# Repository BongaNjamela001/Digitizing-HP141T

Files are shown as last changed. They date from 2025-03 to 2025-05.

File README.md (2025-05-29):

# HP141T Spectrogram Display Project

This repository contains the complete set of files for the HP141T Spectrogram Display project, including hardware designs, simulations, software, and documentation. The project aims to visualize time-domain spectrogram data from the HP141T spectrum analyzer on a touchscreen LCD, replicating the CRT display with a green trace and grid.

## Repository Structure

The repository is organized into the following main folders:

- **PCBs/**: Hardware design files for the HP141T emulator and Signal Conditioning Subsystem.
- **Presentation/**: Materials for project presentations.
- **Report/**: Project report and associated LaTeX files.
- **Results/**: Output data and results from the project.
- **Simulations/**: Simulation files for circuit and signal analysis.
- **Software/**: Python scripts for data processing and GUI implementation.

### PCBs
This folder contains the PCB design files for the project, divided into two subdirectories:

- **HP141T_Emulator/**: KiCad project files and Gerber files for the HP141T emulator PCB.
- **Signal_Conditioning_Subsystem/**: KiCad project files and Gerber files for the Signal Conditioning Subsystem PCB.

### Presentation
This folder includes materials prepared for project presentations:

- **Poster/**: The project poster in PDF format.
- **Oral_Assessment/**: PowerPoint presentation (`.pptx`) for the oral assessment.

### Report
This folder contains the project report and its source files:

- **LaTeX/**: LaTeX source files for the project report.
- **Final_Report/**: Compiled PDF of the final project report.

### Results
This folder stores the output data and results generated during the project. It includes CSV files (e.g., `das-data_01.csv` to `das-data_64.csv`) with time and voltage measurements used for spectrogram visualization.

### Simulations
This folder contains simulation files for circuit and signal analysis:

- **LTSpice/**: LTSpice simulation files for circuit design validation.
- **MATLAB/**: MATLAB scripts and simulation files for signal processing and analysis.

### Software
This folder includes the software developed for the project:

- **DPS/**: Python scripts for data processing (e.g., `spectrogram_display_documented.py`).
- **GUIs/**: Python scripts for graphical user interfaces to interact with the spectrogram display.

## Usage

To explore the repository:

1. **Hardware**: Use KiCad to open the PCB design files in the `PCBs/` folder. Gerber files can be used for manufacturing.
2. **Simulations**: Run LTSpice simulations directly from the `.asc` files, or use MATLAB to execute the signal processing scripts.
3. **Software**: Navigate to the `Software/DPS/` folder to run the Python scripts. Ensure dependencies like `pandas`, `matplotlib`, and `tkinter` are installed. For example:
   ```bash
   python spectrogram_display_documented.py
   ```
4. **Documentation**: View the final report in `Report/Final_Report/` or compile the LaTeX source in `Report/LaTeX/`.

## License

This project is licensed under the MIT License. See the `LICENSE` file for details (to be added).

## Contributing

Contributions are welcome! Please submit a pull request or open an issue to discuss improvements or bug fixes.

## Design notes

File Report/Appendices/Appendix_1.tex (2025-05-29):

% ----------------------------------------------------
% Introduction
% ----------------------------------------------------
\documentclass[class=report,11pt,crop=false]{standalone}
\input{../Style/ChapterStyle.tex}
\input{../FrontMatter/Glossary.tex}
\begin{document}
	% ----------------------------------------------------
	\chapter{Appendix}
	
	\section{Data Acquisition Subsystem Code}
	
	\subsection{\acrshort{das} Macros}
	
	The \acrfull{das} is implemented on the STM32H723ZG microcontroller using embedded C and the STM32 HAL library to sample the horizontal, vertical, and pen-lift signals via ADC1 pins PF10, PF9, and PF8, respectively. A 3-channel \acrshort{dma} stream is used to continuously transfer 16-bit ADC samples into a 402-element buffer, with the \texttt{DMA2\_Stream0\_IRQHandler} managing buffer events via HAL \acrshort{dma} interrupt handling.
	
	\begin{lstlisting}[language=C, label={lst:das-adc-macros}, caption={Showing macros for the \acrshort{adc} channels, \acrshort{dma} and the associated interrupts for handling streaming.}]
		/* ADC Channels */
		#define ADCx_CHANNEL                    ADC_CHANNEL_8  // V_x
		#define ADCx_CHANNEL2                   ADC_CHANNEL_7  // V_y
		#define ADCx_CHANNEL3                   ADC_CHANNEL_6  // V_z
		
		/* DMA Configuration */
		#define ADCx_DMA_CHANNEL                DMA_REQUEST_ADC1 // Master ADC1
		#define ADCx_DMA_STREAM                 DMA2_Stream0
		#define ADCx_DMA_IRQn                   DMA2_Stream0_IRQn
		#define ADCx_DMA_IRQHandler             DMA2_Stream0_IRQHandler
		
		ADC_HandleTypeDef    AdcHandleMaster;
		ADC_HandleTypeDef    AdcHandleSlave;
		
		#define ADC_BUF_SIZE 802 // 802 samples (401 samples/channel)
		volatile uint16_t adc_buffer[ADC_BUF_SIZE] = {0}; // 16-bit for interleaved data
		
		volatile int adc_error_flag = 0;
	\end{lstlisting}

	\subsection{Implementing Direct Memory Access for \acrshort{das}}
	
	The \texttt{adc\_init} function configures ADC1 and ADC2 in double-interleaved mode for continuous 16-bit sampling across three channels, with DMA handling enabled for real-time data acquisition. Although the system is configured to output 32-bit words, the use of a \texttt{uint16\_t} buffer relies on the HAL to extract the lower 16 bits of each sample.
		
	\begin{lstlisting}[language=C, label={lst:das-spectrogram-init-code}, caption={Code snippet of the \texttt{adc\_init} function which configures the double-interleaved operation of the \acrshort{adc}s.}]
		int adc_init(void) {
			ADC_ChannelConfTypeDef sConfig;
			ADC_MultiModeTypeDef multiMode;
			//...
			/* Configure ADC2 (Slave) */
			AdcHandleSlave.Instance = ADCx_SLAVE;
			AdcHandleSlave.Init = AdcHandleMaster.Init; // Same config as master
			if (HAL_ADC_Init(&AdcHandleSlave) != HAL_OK) {
				adc_error_handler();
				return -1;
			}
			
			/* Configure double-interleaved mode */
			multiMode.Mode = ADC_DUALMODE_INTERL_FAST; // Fast interleaved mode
			multiMode.DualModeData = ADC_DUALMODEDATAFORMAT_32_10_BITS;
			multiMode.TwoSamplingDelay = ADC_TWOSAMPLINGDELAY_1CYCLE;
			if (HAL_ADCEx_MultiModeConfigChannel(&AdcHandleMaster, &multiMode) != HAL_OK) {
				adc_error_handler();
				return -1;
			}
			//...
		}
	\end{lstlisting}

	\subsection{Reading Interleaved Data}
	
	\acrshort{adc} data stored in the \texttt{adc\_spectrogram} structure is processed in real-time using \acrshort{dma} half-complete callbacks, such as \texttt{HAL\_ADC\_ConvHalfCpltCallback}. This function reads interleaved $\texttt{V}_\texttt{x}$, $\texttt{V}_\texttt{y}$, and $\texttt{V}_\texttt{z}$ values from the buffer, scales them based on 16-bit resolution, and applies logic for plotting and pen-lift detection using a threshold at mid-scale (32768), with adjustments made for signal inversion and normalization as needed.
	
	\begin{lstlisting}[language=C, label={lst:das-callbacks}, caption={Showing conversion callbacks for processing \acrshort{adc} data when the \acrshort{dma} fills half.}]
		void HAL_ADC_ConvHalfCpltCallback(ADC_HandleTypeDef* AdcHandle) {
			for (int j = 0; j < ADC_BUF_SIZE/6; ++j) {
				uint32_t x_val = adc_buffer[j*3];     // V_x
				uint32_t y_val = adc_buffer[j*3+1];   // V_y
				uint32_t z_val = adc_buffer[j*3+2];   // V_z
				x_val = (x_val * adc_spectrogram->npoints) / 65536; // 16-bit scaling
				y_val = adc_spectrogram->size_y - (adc_spectrogram->size_y * y_val) / 65536;
				z_val = z_val > 32768 ? 1 : 0; // Threshold at mid-scale (~1.65 V)
				if (x_val < 5) prev_x = 0;
				if (x_val > prev_x && z_val == 0) {
					if (pending_normalization) {
						adc_spectrogram->data_normal[x_val] = adc_spectrogram->size_y/2 - y_val;
					}
					adc_spectrogram->data[x_val] = y_val + adc_spectrogram->data_normal[x_val];
					prev_x = x_val;
				}
			}
		}
	\end{lstlisting}
	
	\subsection{Enabling \acrshort{adc}'s and Peripherals on STM32H723ZG}

	The \texttt{HAL\_MspInit} function is implemented to perform essential system-level initializations for the \acrshort{das} using the STM32 \acrshort{hal} framework. It enables clocks for \acrshort{adc}s, GPIOF, and DMA2, and configures the required \acrshort{gpio} pins as analog inputs without pull-up resistors. The function also sets up \acrshort{dma} with 16-bit alignment in circular mode and links it to the \acrshort{adc}, while configuring \acrshort{nvic} interrupts to handle \acrshort{dma} transfer events efficiently.
	
	\begin{lstlisting}[language=C, label={lst:das-callbacks}, caption={Showing conversion callbacks for processing \acrshort{adc} data when the \acrshort{dma} fills half.}]
	void HAL_ADC_MspInit(ADC_HandleTypeDef *hadc) {
		GPIO_InitTypeDef GPIO_InitStruct = {0};
		static DMA_HandleTypeDef hdma_adc;
		
		if (hadc->Instance == ADCx_MASTER) {
			/* Enable clocks */
			ADCx_CLK_ENABLE();0
			ADCx_CHANNEL_GPIO_CLK_ENABLE();
			DMAx_CLK_ENABLE();
			//...
			/* Configure GPIO pins */
			GPIO_InitStruct.Pin = ADCx_CHANNEL_PIN | ADCx_CHANNEL_PIN2 | ADCx_CHANNEL_PIN3;
			GPIO_InitStruct.Mode = GPIO_MODE_ANALOG;
			GPIO_InitStruct.Pull = GPIO_NOPULL;
			//...
			hdma_adc.Init.PeriphDataAlignment = DMA_PDATAALIGN_HALFWORD; // 16-bit
			hdma_adc.Init.MemDataAlignment = DMA_MDATAALIGN_HALFWORD;
			hdma_adc.Init.Mode = DMA_CIRCULAR;
			//...
			__HAL_LINKDMA(hadc, DMA_Handle, hdma_adc);
			
			/* Configure NVIC */
			HAL_NVIC_SetPriority(ADCx_DMA_IRQn, 0, 0);
			HAL_NVIC_EnableIRQ(ADCx_DMA_IRQn);
		}
		//..
	\end{lstlisting}
	
	\section{Digital Processing Subsystem Code}
	
	\subsection{Data Formatting}
	
	To ensure compatibility between different sampling devices (such as the STM32H7 and the Picoscope), the spectrogram data structure—originally developed for an STM32F746G board—was adapted to process and store interleaved data from three ADC channels into a series of \texttt{.csv} files. The \texttt{spectrogram\_to\_csv()} function manages file creation, formats the time-stamped voltage samples, and writes them in blocks of 801 points per file to support downstream processing in the \acrshort{dps} and \acrshort{guis} subsystems.
	
	\begin{lstlisting}[language=C, label={lst:das-csv-file}, caption={Code snippet of the function for storing the interleaved sampling data in a \texttt{.csv}.}]
		int spectrogram_to_csv(spectrogram_t *s, const char *base_filename) {
			if (!s || !base_filename) return -1;
			
			const double sample_period_ms = 0.000138889; // 1 / 7.2 MSPS
			int file_index = 0;
			int point_count = 0;
			char filename[64];
			FILE *fp = NULL;
			
			for (int i = 0; i < s->npoints && !pause_flag; ++i) {
				if (point_count == 0) {
					// Open new file
					snprintf(filename, sizeof(filename), "%s%d.csv", base_filename, file_index);
					fp = fopen(filename, "w");
					if (!fp) return -1;
					fprintf(fp, "Time (ms),V_x (V),V_y (V),V_z (V)\n");
				}
				
				double time_ms = i * sample_period_ms;
				float vx = s->data_x[i] * 3.3f / 65535.0f;
				float vy = s->data_y[i] * 3.3f / 65535.0f;
				float vz = s->data_z[i] * 3.3f;
				
				fprintf(fp, "%.8f,%.8f,%.8f,%.8f\n", time_ms, vx, vy, vz);
				
				point_count++;
				if (point_count >= 801 || i == s->npoints - 1) {
					fclose(fp);
					point_count = 0;
					file_index++;
				}
			}
			
			return 0;
		}
	\end{lstlisting}
	
	\subsection{Using Piecewise Cubic Polynomial Interpolation to Smooth Display}
	
	The proposed design implements the Cubic spline interpolation algorithm which uses piecewise cubic polynomials to define a curve within different segments of the data. The code snippet in listing \ref{lst:dps-spline} illustrates how the frequency domain plot of the signal is smoothed to reduce sharp edges that can occur when using linear interpolation. The program plots the \acrshort{crt}-like background grid on the touchscreen, allowing users to analyse the input signal in the tuning section.
	
	\begin{lstlisting}[language=Python, caption={Code snippet for performing polynomial interpolation in the \acrshort{dps} to the spectrogram a smoother appearance.}, label={lst:dps-spline}]
	from scipy.interpolate import CubicSpline
	#...
	# Perform cubic spline interpolation
	def interpolate_data(time_ms, power_db):
		cs = CubicSpline(time_ms, power_db)
		time_smooth = np.linspace(time_ms[0], time_ms[-1], 1000)  # Increase resolution
		power_smooth = cs(time_smooth)
		 plt.clf()
		ax = plt.gca()
		
		# Plot with CRT styling using spline-interpolated data
		ax.plot(time_smooth, power_smooth, color='limegreen', linewidth=2)
		
		# CRT-like background and grid
		ax.set_facecolor('black')
		fig.patch.set_facecolor('black')
		ax.grid(True, color='gray', linestyle='--', linewidth=0.5)
		
		# Grid divisions: 10 (time), 8 (amplitude)
		time_max = time_ms[-1]
		ax.set_xticks(np.linspace(0, time_max, 11))
		ax.set_yticks(np.linspace(0, 80, 9))
		
		# Labels and title
		ax.set_xlabel('Frequency (GHz)', color='white', fontsize=12)
		ax.set_ylabel('Amplitude (dB)', color='white', fontsize=12)
		ax.set_title('HP141T Spectrogram', color='white', fontsize=14)
		ax.tick_params(axis='both', colors='white')
		
		# Set axis limits
		ax.set_xlim(0, time_max)
		ax.set_ylim(0, 80)
		
		canvas.draw()
		logging.info("Frequency domain plot updated successfully with spline interpolation")
	\end{lstlisting}

	\section{Graphical User Interface Code}

	\subsection{Pause Functionality Implemented on the Single-Board Computer}
	The code snippet below is used to flag the STM32H723ZG connected to the single-board \acrshort{rpi} 4B to pause data sampling. The code also illustrates enabled logging for debugging and getting feedback on the user's actions.
	\begin{lstlisting}[language=Python, caption={Code snippet for function associated with the pause function in latex.}, label={lst:guis-pause-function}]
	# Global pause flag
	pause_flag = False
	
	def pause_recording():
		global pause_flag
		pause_flag = True
		status_label.config(text="Recording Paused")
		logging.info("Recording paused by user")
	\end{lstlisting}

	\subsection{Enabling the \acrfull{phm}, \acrfull{avm} and \acrfull{rwm} Display Modes}
	The \acrshort{phm} tracks and displays the maximum value seen for each data point and is updated per scan. The \texttt{hp141t} Python module includes a \texttt{SpectrumProcessor Class} for updating the \texttt{time\_data} with the maximum value at each index. 
	
	\begin{lstlisting}[language=Python, caption={Code snippet for enabling the \acrshort{phm} when the user presses the \texttt{PHM} button on the screen.}, label={lst:guis-phm}]
		 # Update mode-specific data
		if self.mode == 'PHM':
			np.maximum(self.peak_data, power_db, out=self.peak_data)
			return self.peak_data
		elif self.mode == 'AvM':
			if self.scan_count == 1:
				self.avg_data = power_db
			else:
				self.avg_data = (self.avg_data * (self.scan_count - 1) + power_db) / self.scan_count
			return self.avg_data
		else:  # RwM
			self.raw_data = power_db
			return self.raw_data
	\end{lstlisting} 

	\subsection{System Documentation and Tutorial for Users}
	
	A \texttt{HELP} button is included to enhance the usability of the system, in line with SRO6. The tutorial is displayed in a read-only \texttt{Text} widget and explains the system to users.
	
	\begin{lstlisting}[language=Python, caption={Code snippet for creating a pop-up window with a tutorial when the user interacts with the \texttt{HELP} button.}, label={lst:guis-show-help}]
		def show_help():
			"""Display a tutorial window"""
			help_window = tk.Toplevel(root)
			help_window.title("Help - HP141T Spectrogram Tutorial")
			help_window.geometry("400x300")
			help_window.configure(bg='black')
			
			# Tutorial text
			tutorial_text = """
			=== HP141T Spectrogram Tutorial ===
			
			Welcome to the HP141T Spectrogram Display!
			This system visualizes data from the HP141T spectrum analyzer on a touchscreen LCD.
			
			**Purpose:**
			- Displays time-domain spectrogram data (0 to 80 dB amplitude, time sweep).
			- Replicates the CRT display with a green trace and grid.
			
			**Modes:**
			- **Peak Hold Mode (PHM):** Shows the largest value seen at each time point, updated per scan.
			- **Average Mode (AvM):** Displays the running average of values at each time point, updated per scan.
			- **Raw Mode (RwM):** Shows the latest value, overwriting previous data during each scan.
			
			**Usage:**
			- **Mode Selection:** Tap 'Peak Hold Mode', 'Average Mode', or 'Raw Mode' to switch display modes.
			- **Pause:** Tap 'Pause Recording' to stop updates.
			- **Help:** Tap 'Help' to view this tutorial.
			- Navigate using touchscreen gestures if supported by future updates.
			
			**Notes:**
			- Data is loaded from 'spectrogram_data_X.csv' files in /home/pi.
			- Contact support for issues (log at /home/pi/spectrogram_display.log).
			
			Close this window to return to the display.
			"""
			
			# Create and configure text widget
			text_widget = tk.Text(help_window, bg='black', fg='white', font=('Courier', 10), wrap='word')
			text_widget.insert(tk.END, tutorial_text)
			text_widget.config(state='disabled')  # Make read-only
			text_widget.pack(expand=True, fill='both', padx=10, pady=10)
	\end{lstlisting} 
	\ifstandalone
	\bibliography{../Bibliography/References.bib}
	\printnoidxglossary[type=\acronymtype,nonumberlist]
	\fi
\end{document}
% ----------------------------------------------------

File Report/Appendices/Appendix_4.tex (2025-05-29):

% ----------------------------------------------------
% Introduction
% ----------------------------------------------------
\documentclass[class=report,11pt,crop=false]{standalone}
\input{../Style/ChapterStyle.tex}
\input{../FrontMatter/Glossary.tex}
\begin{document}
	% ----------------------------------------------------
	\chapter{Appendix}

	\section{Graduate Attributes}
		
	\begin{table}[ht!]
		\centering
		\begin{tabular}{|c|m{15em}|m{20em}|}
			\hline
			\textbf{GA} & \textbf{Requirement} & \textbf{Justification and Section in Report} \\
			\hline
			1 & \textbf{Problem-solving} &
			The project focuses on digitizing and modernizing the HP141T spectrum analyzer by identifying engineering challenges such as analog signal emulation, safe ADC interfacing, and display integration. Problem-solving was guided by engineering fundamentals to replicate the HP141T's behavior while addressing obsolescence. \textit{See Chapters 2 and 3.} \\
			\hline
			4 & \textbf{Investigations, experiments and data analysis} &
			The project involved unit, integration, and acceptance testing of the emulator and digitized system. Measurements from analog signals were sampled, processed, and evaluated using oscilloscope and data analysis tools. Results were used to confirm emulation fidelity. \textit{See Chapter 5.} \\
			\hline
			5 & \textbf{Use of engineering tools} &
			Modern tools such as KiCad (PCB design), STM32CubeIDE (embedded development), Python (data processing and GUI), and the Picoscope software were used throughout. These tools enabled simulation, design validation, and visualization. \textit{See Chapter 3.} \\
			\hline
			6 & \textbf{Professional and technical communication} &
			Weekly Microsoft Teams meetings were held with the supervisor, and updates were communicated clearly. Project progress, testing results, and implementation steps were documented in the report. A full BoM and Gantt chart were created. \textit{See Chapter 1 and Appendices.} \\
			\hline
			8 & \textbf{Individual work} &
			All major system components—hardware design, firmware development, data processing, and GUI rendering—were independently developed. Feedback was incorporated iteratively throughout the project. \textit{See entire report.} \\
			\hline
			9 & \textbf{Independent learning ability} &
			The project required in-depth understanding of legacy analog circuitry, signal conditioning, ADC interfacing, and embedded development. This knowledge was self-acquired through datasheets, application notes, and literature. \textit{See Chapter 2 and 3.} \\
			\hline
		\end{tabular}
		\caption{Summary of Graduate Attributes Achieved in the Digitized HP141T Project}
		\label{tab:graduate-attributes-hp141t}
	\end{table}

	\ifstandalone
	\bibliography{../Bibliography/References.bib}
	\printnoidxglossary[type=\acronymtype,nonumberlist]
	\fi
\end{document}
% ----------------------------------------------------

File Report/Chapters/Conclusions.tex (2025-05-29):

% ----------------------------------------------------
% Conclusions
% ----------------------------------------------------
\documentclass[class=report,11pt,crop=false]{standalone}
\input{../Style/ChapterStyle.tex}
\input{../FrontMatter/Glossary.tex}
\begin{document}
% ----------------------------------------------------
\chapter{Conclusions \label{ch:conclusions}}

The experimental testing of the digitized HP141T system, incorporating the HP8555A and HP8552B plug-in sections, has yielded valuable insights into its performance and alignment with the specified functional requirements. The results demonstrate a mixed outcome, with significant achievements in certain subsystems tempered by challenges in others, necessitating further refinement.

The HP141T System Test Results, utilizing the Siglent SDG1010 waveform generator and Picoscope 2204 USB oscilloscope, successfully approximated the vertical output with satisfactory accuracy, achieving a peak-to-peak voltage deviation of approximately 10\% from the expected values. The Picoscope proved to be a reliable measurement tool, and the sinusoidal approximation at 10 kHz provided a suitable basis for testing, despite limitations in replicating the full range of the original HP141T outputs. However, the horizontal and pen-lift outputs could not be accurately emulated due to waveform shape discrepancies and voltage range constraints, highlighting the need for alternative hardware or calibration methods to fully replicate the HP8552B behavior.

The HP141T Emulator Subsystem Test Results revealed significant deviations from expected performance, attributed to the use of E6 series resistors and adjusted capacitor values instead of the recommended E24 series. The failure of the emulator to produce the correct vertical (0 to 3.0 V), horizontal (±4.75 V sawtooth), and pen-lift (0 to 14 V) outputs underscores the sensitivity of the XR2206-based design to component tolerances. While the power rails met specifications, further iterations are required to enhance waveform fidelity and ensure compatibility with downstream systems.

In contrast, the SCS performed admirably, with unit tests confirming its ability to invert and scale the vertical input from -0.8 V to 0 V to the ADC-compatible 0 V to 3.3 V range. The subsystem handled noisy inputs effectively, maintaining output within the desired range, though clipping effects were observed at higher amplitudes, mitigated somewhat by increasing the input frequency to 300 kHz. These results validate the SCS design and its robustness against real-world signal variations.

The Data Acquisition Subsystem DAS, adapted to use the Picoscope 2204A due to the unavailability of the STM32H723ZG microcontroller, successfully generated CSV files with 6257 data points at a 3.3 kHz sampling rate, exceeding the required 801 samples per second. This adaptation, while affecting real-time performance, ensured data integrity for downstream processing, demonstrating the system's flexibility in leveraging alternative hardware.

The Digital Processing Subsystem DPS and Graphical User Interface Subsystem GUIS, implemented on the Raspberry Pi 4B, met all unit test criteria. The DPS accurately scaled voltages to decibels, retained peak amplitudes, averaged spectrograms, and interpolated sparse data, while the GUIS provided near real-time updates (50-100 ms latency), reliable mode switching, and a faithful 8x10 grid display with CRT styling. These results affirm the software's robustness and usability, closely emulating the original HP141T's visual output.

Overall, the digitized HP141T system achieves a high degree of fidelity in its software components (DPS and GUIS) and signal conditioning SCS, meeting the functional requirements for display accuracy, responsiveness, and user interaction. However, hardware-related limitations in the emulator and original system approximation highlight areas for improvement, particularly in component selection and waveform emulation. Future work should focus on refining the HP141T Emulator with precise E24 components, exploring higher-voltage waveform generators for the pen-lift output, and optimizing the DAS for real-time performance with the intended microcontroller. These enhancements will further align the system with the original HP141T's capabilities, ensuring a comprehensive and accurate digital replica.

% ----------------------------------------------------
\ifstandalone
\bibliography{../Bibliography/References.bib}
\printnoidxglossary[type=\acronymtype,nonumberlist]
\fi
\end{document}
% ----------------------------------------------------

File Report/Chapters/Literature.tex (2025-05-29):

% ----------------------------------------------------
% Literature Review
% ----------------------------------------------------
\documentclass[class=report,11pt,crop=false]{standalone}
\input{../Style/ChapterStyle.tex}
\input{../FrontMatter/Glossary.tex}
\begin{document}
\ifstandalone
\tableofcontents
\fi
% ----------------------------------------------------
\chapter{Literature Review \label{ch:literature}}
\vspace{0.25cm}
% ----------------------------------------------------
The aim of this chapter is to conceptualize the operation of spectrum analyzers and establish a theoretical foundation for the frequency analysis techniques applied to produce the correct output. This conceptualization is then integrated with a broader review of digitizing and modernizing the display of spectrum analyzers.

In circumventing design limitations of spectrum analyzer displays, it is prudent to survey the most suitable hardware components. This is particularly true for the case where electronic components are required to perform in a broad frequency bandwidth. For example, for high frequency signals, the Nyquist theorem indicates that the ADC is required to have a sample at a frequency that is more than double the frequency of the output signal. Furthermore, the challenge of presenting signals in the frequency domain using electronics exists due to the fact the input signal to the ADC holds information about frequency in the time domain. Therefore, the investigation of literature that is presented in this chapter aims to provide a motivation for the design decisions taken in digitizing and modernizing the HP141T display.

The chapter begins with an evaluation of the frequency domain analysis theory that is applied in the operation of signal analyzers. Then, the different principles that distinguish different types of analyzers are explored to form the basis understanding the expected behaviour of a spectrum analyzer with specific settings. Following descriptions of the operation of spectrum analyzers from literature, the chapter includes a review of the investigation into different techniques for digitizing analyzer displays. This also includes a review of the different electronic components and techniques for digitizing frequency information in order to survey available hardware options that can be selected for a cost effective implementation. Finally, a broad discussion is included on different types of displays for analyzers in literature and a critique of the literature is provided to outline the purpose of the proposed design. 

\section{Mitigating Spectrum Analyzer Obsolescence: A Historical Perspective}

\subsection{Introduction to Spectrum Analysis}

A spectrum analyzers \acrshort{sa}s is a critical instrument for investigating properties of physical phenomena that can be interpreted through power and frequency characteristics of analog signals derived from voltage measurements. This project differentiates between spectrum analyzers and oscilloscopes such that spectrum analyzers are instruments that display waveforms in the frequency domain and oscilloscopes as instruments that operate in the time domain. However, the paper recognizes their significance in signal processing applications, as well as some of the shared similarities in their subsystems. 

As such, the following section is a review of the history and applications of spectrum analyzers and oscilloscopes to establish the context of the project. By assimilating literature on the applications of these instruments in engineering, the section also aims to formulate design guidelines from previous works that can improve the operation of the digitized HP141T, thereby satisfying user and functional requirements. 

\subsection{Early Developments in Waveform Analysis}

The evolution of \acrshort{sa}s is closely linked to that of the oscilloscope. In a review of the history and technology of oscilloscopes, Pereira attributed the invention of the electromagnetic oscillograph to the French physicist, Andr\'{e}-Eugene Blondel \cite{pereira2006}. Oscillographs were devices that used a pen attached to a moving coil to trace an ink record on a rotating paper chart \cite{pereira2006}. According to Herres, the motivation for the invention of oscillographs was to extract waveforms from acoustic and electrical phenomena, however, the devices had a severely limited frequency response and bandwidth because of the inertia of the pen and ink recording equipment \cite{herres2020}. Ultimately, the operation of these devices was restricted by the working principle based on mechanical devices which limited the bandwidth in the range of $10$-$\SI{19}{\hertz}$ \cite{pereira2006}.

\begin{wrapfigure}{r}{0.5\textwidth}
	\centering
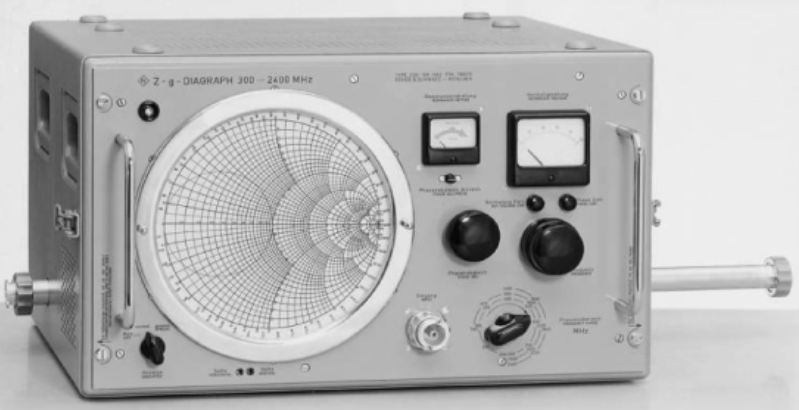
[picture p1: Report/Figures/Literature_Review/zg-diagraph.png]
	
	\caption{The Z-G Diagraph by developed by Rohde \& Schwarz with a Schmidt chart for measuring complex parameters \cite{rytting2008arftg}.}
	\label{fig:zg-diagraph}
\end{wrapfigure}

Following the invention of the oscillograph, available waveform analysis tools included contact diode and vacuum tubes as the only form of signal detectors \cite{vollinger2023}. Technologies such as the slotted line and phase bridges became the standard instruments for measuring amplitude and frequency but were often slow and tedious \cite{rytting2008arftg}. In 1933, Rohde \& Schwarz developed the improved Z-G system which was the first to directly indicate complex parameters on a Schmidt chart as shown in figure \ref{fig:zg-diagraph} \cite{rytting2008arftg}.  

\subsection{Advancements in Spectrum Analysis Technology}
 
The first commercially available real-time signal analyzers (\acrshort{rtsa}s) were introduced in the 1960s by Federal Scientific to process data up to $\SI{20}{\kilo\hertz}$ through a single filter that could change modes in milliseconds \cite{deery2007}. These devices were designed for analyzing mechanical faults and failures in rotating machinery and for investigating vibratory motions of components, systems and structures \cite{deery2007}. In contrast to the the \acrshort{sa}s introduced in the 1960s for characterizing rotary machinery, this paper is focuses on \acrshort{sa}s that were designed for displaying wide-band signals up to the K-band of microwave signals. 

Rapid progress in semiconductor technology and microwave elements laid a foundation for the developed first waveform instrumentation devices with $\SI{1}{\giga\hertz}$ bandwidth \cite{vollinger2023}. With the advent of wireless network technologies, \acrshort{sa} developments became focused on high frequency instrumentation which had to meet testing requirements of first generation technologies such as the \acrfull{amps} operated at frequencies at $\SI{800}{\mega\hertz}$ to $\SI{900}{\mega\hertz}$. Vector network analyzers were introduced as an extension of spectrum analyzers capable of displaying amplitude and phase relative to a reference signal \cite{helfrick2012}. 

\subsection{Early Modifications to Spectrum Analyzers (1960s - 1980s)}

\begin{wrapfigure}{l}{0.6\textwidth}
	\centering
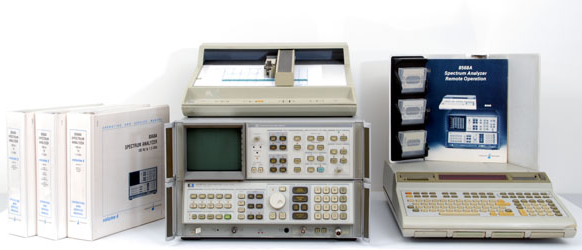
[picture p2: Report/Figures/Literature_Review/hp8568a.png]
	
	\caption{The HP8568A spectrum analyzer which was the first spectrum analyzer from Hewlett-Packard Company to include a microprocessor in the 1970s.}
	\label{fig:hp8568a}
\end{wrapfigure}

Motivated by applications in network analysis and microwave engineering, Hewlett-Packard developed the first fully calibrated spectrum analyzer that capable of sweeping broad frequency ranges \cite{adam1984microwave}. After the introduction of easily-operated wideband network analyzer equipment in 1967, Hewlett-Packard Co. released a network analyzer with a range of $\SI{100}{\kilo\hertz}$ to $\SI{110}{\mega\hertz}$. In particular, the company released the Model 8407A which could resolve amplitude of up to $\SI{0.05}{\decibel}$ on a plug-in polar \acrfull{crt} display to show amplitude and phase \cite{rytandnetwork1969}. The aim of the display was so that the device could be used with Smith chart overlay, or reflection coefficient measurements \cite{rytandnetwork1969}. 

\begin{wrapfigure}{r}{0.40\textwidth}
	\centering
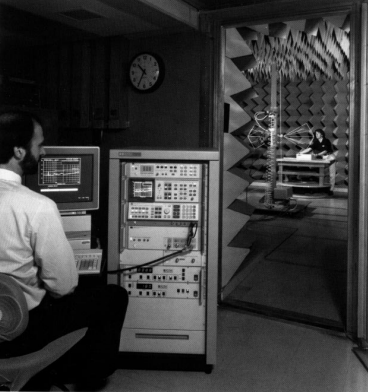
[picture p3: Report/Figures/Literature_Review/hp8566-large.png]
	
	\caption{Illustrating the size of early spectrum analyzer setups. Digitization and modernization of these devices was also focused on reducing their size in order to improve portability.}
	\label{fig:hp56xx-large}
\end{wrapfigure} 

In 1982, D'Addario proposed the implementation of Hewlett-Packard Model 8410A network analyzer as a reflectometer in a system which included an Apple II Plus computer for performing computations of the short-open-load method of calibrating and correcting errors of signals in the S-band of the microwave region of the electromagnetic spectrum \cite{d1982computer}. D'Addario stated that the advantage of implementing a computer-based system was in the software substituted a short delay line for open circuit calibration \cite{d1982computer}. In addition, the software was mostly in Applesoft Basic that featured assembly language subroutines for performing complex arithmetic and controlling the interface \cite{d1982computer}. Similarly, the proposed design in this project aims to exploit the advantages of computerization by introducing functions and libraries for performing digital signal processing tasks and controlling the \acrfull{gui}. 

Another modification to the HP8410 was performed by NASA's Terry and Kunath in 1990, where the \acrshort{sa} was used as an automated far-field antenna range receiver \cite{terry1990}. The system included external mixers capable of harmonic mixing up to $\SI{18}{\giga\hertz}$, \acrfull{adc}s, and interfaced with an external computer \cite{terry1990}. Terry and Kunath noted that the phase and amplitude signals could be converted to digital signals by using either \acrshort{adc}s or by using a digital voltmeter \cite{terry1990}. The authors used a HP308 personal computer with two processors that operated in the DOS 3.3 and HP Basic 5.0 environments, respectively \cite{terry1990}. The computer was employed as the system controller with programs for creating and editing control files for swept frequency, viewing radiated power level data, and running tests with parameters saved in files to be executed or edited at a later time \cite{terry1990}. Consequently, the designer needs to consider file formats, file sizes and file transmission in the process of digitizing a \acrshort{sa}. This is particularly true when the system processes are performed across different devices and programs which may support different file formats and file sizes. 
 
\begin{wrapfigure}{l}{0.6\textwidth}
	\centering
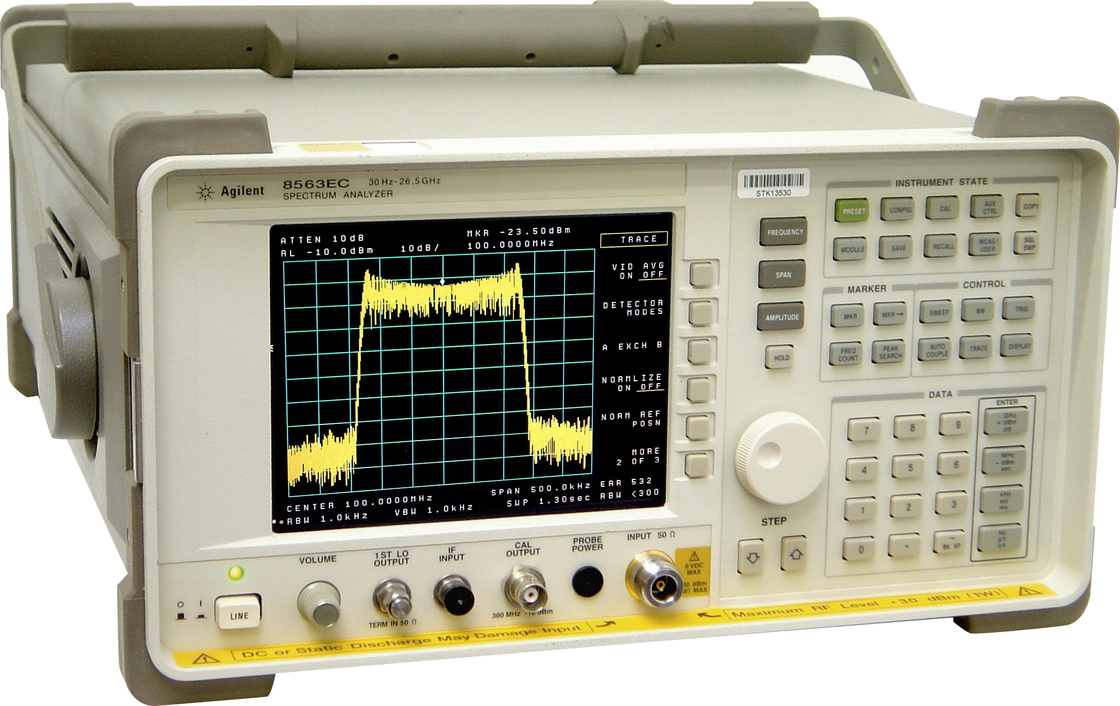
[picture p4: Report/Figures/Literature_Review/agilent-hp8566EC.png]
	
	\caption{The Agilent 8560EC is shown with a \acrshort{lcd} display. This was an improvement over the 8560E model which had a \acrshort{crt} display.}
	\label{fig:agilent-hp8560e}
\end{wrapfigure} 

\subsection{Commercial Digitization of Spectrum Analyzers}

HP85XX spectrum analyzers replaced the HP84XX analyzer series as the first \acrshort{sa}s with synthesized frequency sweeps and an \acrshort{adc} converter for sampling a video signal and displaying it on a \acrshort{crt} screen. The HP85XX series expanded the capabilities of spectrum analyzers, however, earlier versions of these devices were large as shown in figure \ref{fig:hp56xx-large}, where a technician is shown alongside a HP8566B \acrshort{sa} at the heart of two EM1 receivers \cite{hp8566}. Significant improvements to this series of \acrshort{sa}s were realised over previous versions when the HP8568A automatic \acrshort{sa}, shown in figure \ref{fig:hp8568a}, was introduced with a microprocessor controlling its operation. 

In the 2000s, Agilent Technologies mordenized the front and rear panels of HP8560E Model spectrum analyzers,  by introducing \acrshort{lcd} color display interfaced with a \acrshort{lcd} driver board and \acrshort{vga} port located that did not require a user interface \cite{hp8560ec}. Further additions included \acrshort{adc} circuitry integrated into the controller board \cite{hp8560ec}. These improvements also translated into better portability of the system as shown in \ref{fig:agilent-hp8560e}. 

\subsection{Obsolescence Mitigation and Modernization Strategies}

Overtime as prices of new spectrum analyzers increased rapidly, researchers opted to use older \acrshort{sa}s instead of replacing them. Research into strategies for mitigating risks related to the obsolescence of older \acrshort{sa} models was conducted by Hoppin in 2002, where particular focus was allocated to HP8566/68 \acrshort{sa}s in automated test equipment \cite{hoppin2002}. Hoppin stated that dependence on obsolete and unsupported equipment increased the risk of system and that as \acrshort{sa}s aged, the time required for repair and the cost of replacement increases rapidly \cite{hoppin2002}. As a result of the inevitable obsolescence, Hopping proposed three strategies for dealing with the aged devices, namely, the \textit{stockpile}; the \textit{redesign}; and \textit{migration} strategies. The stockpile strategies requires industry organizations to identify sources of spare replacement components and instruments, and offer repair and calibration services \cite{hoppin2002}. 

This project follows a strategy similar to the redesign strategy proposed by Hoppin in which automated test equipment program managers are required to assess the feasibility of introducing replacement instrument specifications, feature and capability requirements \cite{hoppin2002}. Hoppin noted that one of the risks of applying the redesign strategy is that software projects are notoriously hard to manage to scope, budget and schedule \cite{hoppin2002}. Additionally, since the devices have aged significantly, the languages, tools and methods originally used may be lost, requiring designers to apply reverse engineering techniques \cite{hoppin2002}. To mitigate the costs from applying the redesign process, Hoppin described three main components that need to be considered, namely, test code creation, test instrumentation, purchase and integration, and revalidation measurements and results \cite{hoppin2002}. 

In a similar research published in 2010, Wolle discussed the various aspects related to replacement of obsolete instruments to overcome the challenges that arise when newer versions are not compatible with previous systems \cite{wolle2010}. In the paper, Wolle postulated that an emulation strategy can help designers to incorporate new test instruments to migrate from obsolete instruments \cite{wolle2010}. In addition, Wolle noted that when assessing version migration strategies, modernizing test equipment typically has much higher costs but leads to greater reliability and faster tests \cite{wolle2010}. This was first noted by Hoppin who detailed two risks of implementing a migration strategy as low compatibility and disagreement in measurement results due to differences in architectural and measurement methods between legacy and newer-generation platforms \cite{hoppin2002}.

In a 2014 paper by Iglesias et al., the high cost of spectrum analyzers is also noted as a primary motivation for further developing spectrum analyzer designs \cite{iglesias2014}. Iglesias et al. also indicated that because \acrshort{sa}s employ non-invasive methods to detect machine failures in real-time, the devices need to be continually upgraded to reduce failures by improving the efficiency of industrial monitoring systems \cite{iglesias2014}. Following the motivation for improving \acrshort{sa}s, Iglesias et al. postulated that modernization of \acrshort{sa}s was primarily enabled by the fast evolution of \acrshort{adc}s and \acrfull{dsp}s which offer the opportunity to implement multiple methods for spectrum estimation such as Barlett and Welch's methods for averaging periodograms \cite{iglesias2014}. The authors listed devices such as \acrfull{fpga}s, \acrfull{asic}s, general-purpose \acrshort{cpu}s, and \acrfull{gpu}s as feasible candidates for digitizing \acrshort{sa}s \cite{iglesias2014}, however, \acrshort{asic}s were listed as the best implementation with respect to area, power, and speed \cite{iglesias2014}. 
%Continuing to as a pioneer in spectrum analysis in the 1980s, the Hewlett-Packard Company launched the HP8510 \acrfull{vna} System that featured an on-board computer that performed error correction of all parameters in real-time \cite{adam1984microwave}. The full \acrshort{sa} system had an extended frequency range with a single-sweep capability of $\SI{45}{\mega\hertz}$ to $\SI{26.5}{\giga\hertz}$. The measurement and computational power of the HP8510A vector analyzer was provided by microprocessor-based control which enabled the system to offer $\SI{80}{\decibel}$ to $\SI{100}{\decibel}$ range. 
\subsection{Conclusion}

In conclusion, the evolution of spectrum analyzers is characterized by advancements in metrological accuracy in waveform analysis, a migration from analog to digital processing, as well as improvements in functionality and hardware of the user interface. From early mechanical oscillographs to modern digital spectrum analyzers, each technological advancement has been motivated by the need for higher frequency capabilities and improved usability. Technological advancements have culminated in the introduction of computerized control using microprocessors and \acrshort{adc}-based systems that support more efficient signal analysis in the digital time domain.

A primary conclusion that can be drawn from the historical review of \acrshort{sa}s is that modernization strategies for obsolete instruments must balance cost, functionality, and compatibility with newer technologies. \acrshort{sa}s and network analyzers like the HP8410A and HP8568A introduced microcontrollers to automate functions. More recent trends that were introduced with Agilent Technologies' \acrshort{sa}s emphasized \acrshort{gui}s, software-based processing, and integration with digital communication protocols. 

In this project, the digitization of the HP141T spectrum analyzer builds on the primary ideas presented in history on the modernization of spectrum analyzers. Similar to implementations in history, the design proposed in this paper leverages modern single-board computing, digital displays, and software-based signal processing techniques for implementing the redesign strategy for circumventing the obsolescence of the \acrshort{sa}. Furthermore, this project aims to retain the core measurement functionalities of the original device while introducing intuitive graphical interfaces and improved data handling capabilities. The following sections discuss similar works and the challenges that researchers overcame in digitizing and modernizing spectrum analyzers.

\section{A Preview of the Operation of Spectrum Analyzers to Establish the Context for Digitization and Modernization}

Formulating an understanding of the internal operation of the HP141T system is critical for extending functionality through digitization and modernization. In this regard, this project establishes the context of the term digitization as the development of a system which converts the analog signals from the \acrshort{sa} into digital values that are processed on a computer. The context for the term \texttt{digitization} and its usage were explored through literature as described in this section. Key related works were collated and focus is placed on detailing the internal path of an analog signal through the major components of \acrshort{sa}s in general.

The term \textit{modernization} is also clarified through collated literature. In particular, this section details features of modern \acrshort{sa}s and their user interfaces which largely depend on the employed display type. By redesigning the display of the HP141T, the project aims to improve the overall performance of the system with respect to power consumption, ease-of-use, portability, and signal processing features. Changing the display from \acrshort{crt} to \acrshort{lcd} can be considered as a partial fulfilment of modernization, while ensuring that analog outputs from the HP141T can be stored and retrieved for processing at a later time is forms part of the digitization of the system.

To establish a context for these terms, this section begins by differentiation between the different types of \acrshort{sa}s while focusing on the key operational principles that govern the behaviour of the HP141T. Then, the section details the purpose of primary components in spectrum analyzers to formulate a steps for digitizing the system from literature. The section concludes with findings on features of modern spectrum analyzers that differentiate them from older models, and challenges that related works overcame during the modernization process.  

\subsection{Conclusion}

This section has provided a foundational understanding of the HP141T spectrum analyzer’s internal operation, establishing a critical context for its digitization and modernization. By defining digitization as the conversion of analog signals into digital values for computer-based processing, and modernization as the enhancement of system performance through improved power efficiency, usability, portability, and signal processing capabilities—exemplified by the transition from CRT to LCD displays—the project’s objectives have been clearly framed. The literature review has differentiated spectrum analyzer types, emphasizing the HP141T’s operational principles, and outlined the roles of primary components, offering a structured pathway for digitizing its analog outputs for storage and later retrieval.

Furthermore, the analysis of modern spectrum analyzer features, such as advanced user interfaces and highlights the potential improvements achievable through redesigning the HP141T’s display. Insights from related works reveal challenges overcome during modernization, including signal fidelity preservation and hardware-software integration, which inform the project’s approach. Collectively, these findings underscore the feasibility of enhancing the HP141T’s functionality while addressing the complexities of digitizing legacy systems, setting the stage for subsequent experimental and developmental phases.

% ----------------------------------------------------
\ifstandalone
\bibliography{../Bibliography/References.bib}
\printnoidxglossary[type=\acronymtype,nonumberlist]
\fi
\end{document}
% ----------------------------------------------------

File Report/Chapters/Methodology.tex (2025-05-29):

% ----------------------------------------------------
% Introduction
% ----------------------------------------------------
\documentclass[class=report,11pt,crop=false]{standalone}
\input{../Style/ChapterStyle.tex}
\input{../FrontMatter/Glossary.tex}
\begin{document}
	% ----------------------------------------------------
	\chapter{Methodology \label{ch:meth}}
	%\epigraph{Philosophers have hitherto only interpreted the world in various ways; the point is to change it.}%
	%    {\emph{---Karl Marx}}
	%\vspace{0.5cm}
	% ----------------------------------------------------
	
	%\lipsum[1]
	\section{Methodology Outline}
	
	This chapter details the design process and approach employed in achieving the aim of the project which is to  digitize and modernize the HP141T display by replacing the \acrshort{crt} monitor with a \acrshort{lcd} touchscreen display that offers different functions and modes of operation. Design decision are also documented here, showing the considerations that were made based on the operation and outputs of the HP141T spectrum analyzer and ensuring that the newly integrated display is compatible with the device's hardware. For example, the design required selection of the digital hardware for processing the analog voltage signals from the \acrshort{sa}. The selection of the digital processor made from single-board computers such as the Raspberry Pi 4 Model B, microcontrollers like the STM32F4 boards, \acrshort{fpga} such as the Artix-7 from Xilinix, or a heterogeneous digital processor which consists of a combination of these options. 
	
	Other considerations were made regarding the electronic circuits for converting the auxiliary output voltages from the HP141T to the appropriate voltage level for the operation of \acrshort{adc}. This chapter describes how together, the \acrshort{adc} and digital processor form a crucial part of the system. Additionally, the chapter details the software development kit (\acrshort{sdk}) and associated coding language that was used. The selection of the development framework depended on the choice of processor and digital processing algorithms that were required to fulfil the project requirements. For example, assuming that a \acrshort{fpga} is the chosen digital processor, the  \acrshort{sdk} would include tools such as the AMD Vivado and electronic design automation (\acrshort{eda}) software and the choice of coding language between Verilog, VHDL, and SystemVerilog would depend on how comfortable the developer is in representing digital processing algorithms, such the \acrshort{dft}, using the chosen language. 
	
	Overall, this chapter documents an overview of the design methodology and different phases in the design process. The design process followed a variation of V-Model in which a series of iterative phases was implemented with a process checking mechanism. The chapter begins by highlighting the design stages and modularization of the system. Thereafter, the chapter includes an assessment of the project requirements detailed in introductory section. Finally, the chapter describes the use of findings from the review of requirements in informing the design decisions and specifications.  
	
	\section{Phases in the Design Process}
	
	The design process was decomposed into four iterative stages as illustrated in Figure \ref{fig:design-stages-diagram} below. The first stage documented the digitization requirements and listed examples of modern \acrshort{sa}s in order to define the requirements for modernization. As shown in the methodology overview diagram, the first stage also included thorough investigation into methods that have been implemented in literature for upgrading the functions and performance of \acrshort{sa}s. A theoretical framework for relevant information about signal processing was also formulated based on the literature to ensure that the display modes and functions were consistent with the mathematically derived expected outputs in the system. 
	
	\begin{figure}[!ht]
		\centering
		\label{fig:design-stages-diagram}
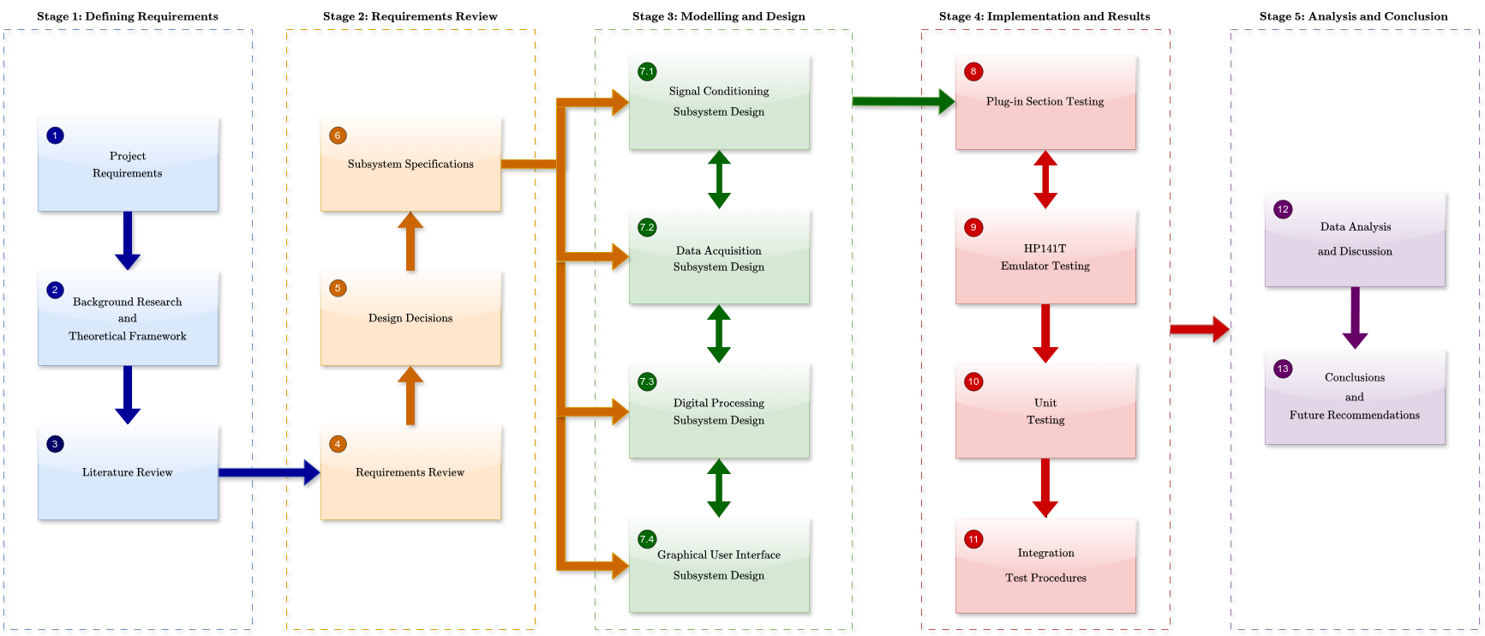
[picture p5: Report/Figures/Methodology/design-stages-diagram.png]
		
		\caption{Methodology overview showing different stages in the iterative design process that was applied as a variation of the V-Model.}
	\end{figure}
	
	The second stage in the design process involved a review of the user requirements specifications detailed in chapter \ref{ch:intro}. The aim of this step in the methodology was to clarify the desired functions of the upgraded spectrum analyzer and to inform the design decisions with respect to the digital hardware and software development for digital signal processing. Additionally, the requirements review was employed in modularizing the design into four subsystems including, the Analog-to-Digital Conversion, Digital Processing, Screen and User Interface subsystems. 
		
	Stage 3 of the design process dealt with the design specifications of each of these subsystems by further decomposing each module into smaller hardware and software components. Each function is tested against a requirement in Stage 4 where each design specification was verified and the operation of the integrated system was tested to ensure that the interfaces between the subsystems was configured correctly. 
	
	In general, implementation of the design process adhered to the following design steps detailed in the project brief and are associated with the user requirement specifications:
	
	\begin{enumerate}
		\item 
		Surveying the HP141T display and other outputs.
		\item 
		Surveying single-board computers and touchscreen options.
		\item 
		Phase One: establish a basic XYZ replica or HP141T emulator.
		\item 
		Phase Two: implement averaging and peak hold options.
		\item 
		Phase Three: annotate display axes.
		\item 
		Phase Four: determine the appropriate instrument settings. 
		\item 
		Phase Five: design new annotations for display taking instrument or operator manual inputs into account.
		\item 
		Phase Six: include more tutorial and operational instructions using.
	\end{enumerate}
	
	In finalizing the design process of the upgraded \acrshort{sa}, results from acceptance tests were assimilated and a conclusion was drawn. Then, based on the outcomes of the project, future recommendations were made for future iterations of the upgrade \acrshort{sa} system. Overall, the stages of the methodology included:
	
	\begin{itemize}
		\item 
		Stage 1: Defining Requirements
		\item 
		Stage 2: Requirements Review and System Overview
		\item 
		Stage 3: Modelling and Design
		\item 
		Stage 4: Implementation and Results
		\item 
		Stage 5: Analysis and Conclusion 
	\end{itemize}

	The first four stages of the design process were performed iteratively as a variation of the V-Model in which risk analysis was performed at each step, similar to the Spiral Model for design processes. Each iteration aimed at producing a new version of the upgraded HP141T display and a single conclusion was made when a satisfactory prototype was established.

	\section{Requirements Review}
	
	This section aims to clarify the scope of the project and produce a technical formalization of the user requirements specifications. The section begins by giving context to the term modernization by investigating the properties of modern \acrshort{sa}s. Then, the section breaks down the user requirements into categories relating data acquisition, processing and display. Finally, the section concludes with a review of the requirement for developing a HP141T emulator. 
		
	\subsection{Comparing the HP141T System to Modern Spectrum Analyzers}
	
	The first user requirement deals with the modernization of the HP141T system. The aim of this section is to review this requirement and to give clarification on the context of the use of "modernization" in this project. To achieve this objective, the section begins with a description of the HP141T system and the functions that differ from "modern" spectrum analyzers, such as the range of hand-held \acrshort{sa}s by FieldFox, and the N9000B CXA \acrshort{sa} manufactured by Keysight\textregistered. The section concludes with a summary table comparing the features of the HP141T system and modern spectrum analyzers. 
	
	The HP141T system is equipped with three plug-ins, namely the 8555A \acrshort{rf} section which operates in the microwave region of the electromagnetic spectrum, the 8552B \acrshort{if} section and the Model 141T display which includes the \acrshort{crt} monitor. The three plug-ins operate in unison to electronically scan signals in the time-domain and provide a visual representation of the input signal's amplitude in the frequency domain on the \acrshort{crt} monitor \cite{HP8555A}. Amplitude can be represented on a logarithmic ($\si{\decibel\meter}$) or linear scale ($\si{\milli\volt}$). 
	
	The 8555A and 8552B plug-ins apply principles of heterodyning spectroscopy, allows high frequency input signals with frequencies in the K-band of the microwave portion of the electromagnetic spectrum (i.e. $\SI{18}{\mega\hertz}$) \cite{harris2003}. As noted from literature in the previous chapter, spectrum analyzers which rely on the \acrshort{fft} by sampling the continuous input signal and performing the Fourier transform on $N$ total samples typically deal with signals that have lower frequencies. This is because \acrshort{sa}s that employ the super-heterodyne principle like the HP141T determine the spectrum directly by analysis in the frequency domain and not from the time-dependent characteristics of the input signal. This is achieved by using a super-heterodyne receiver comprised of a mixer and tunable local oscillator (\acrshort{lo}) which convert the input signal to an intermediate frequency as illustrated in figure \ref{fig:heterodyne-rauscher} \cite{rauscher2007}. 
	
	\begin{figure}[!ht]
		\centering
		\label{fig:heterodyne-rauscher}
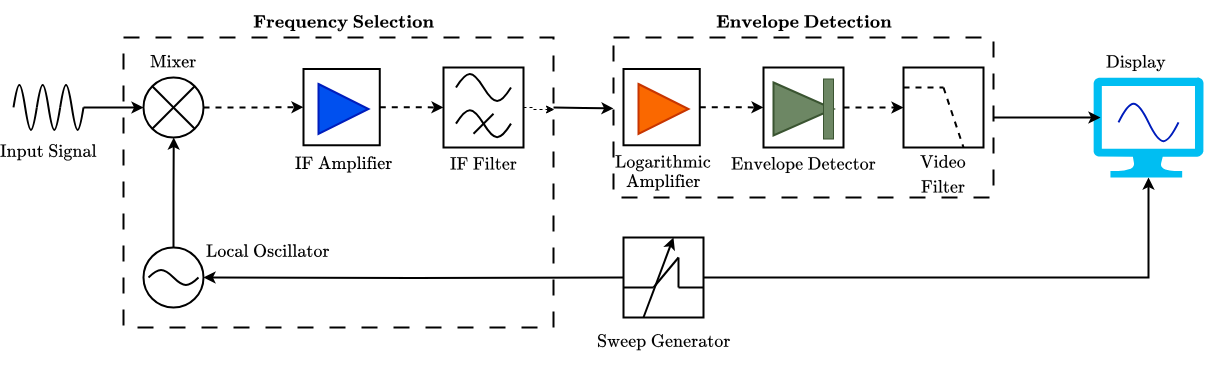
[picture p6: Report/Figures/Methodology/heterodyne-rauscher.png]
		
		\caption{Heterodyne Spectrum Analyzer Block Diagram.}
	\end{figure}
	
	As noted in the literature review, most modern \acrshort{sa}s are real-time spectrum analyzers \acrshort{rtsa} which are a special case of vector spectrum analyzers (\acrshort{vsa}) that use the super-heterodyne principle but digitize the input signal at the intermediate frequency, as shown in Figure \ref{fig:vector-analyzer-rover}, using a bandpass filter which can behave like a pre-select filter to limit distortions that arise from the mixer and shows the result in real-time. The advantage of digitizing the output of the \acrshort{if} section is that it enables large a input range of up to $\SI{50}{\mega\hertz}$ which can be analyzed in the time and frequency domain using digital signal processing techniques \cite{rovers2006}. Much like \acrshort{fft} analyzers, vector analyzers are limited by the minimum and maximum sampling rate at which the \acrshort{adc} can operate. Additionally, exceedingly high sampling rates can lead to aliasing which causes frequencies outside of the bandwidth to fold into the frequency band \cite{rovers2006}. 	

	\begin{figure}[!ht]
		\centering
		\label{fig:vector-analyzer-rover}
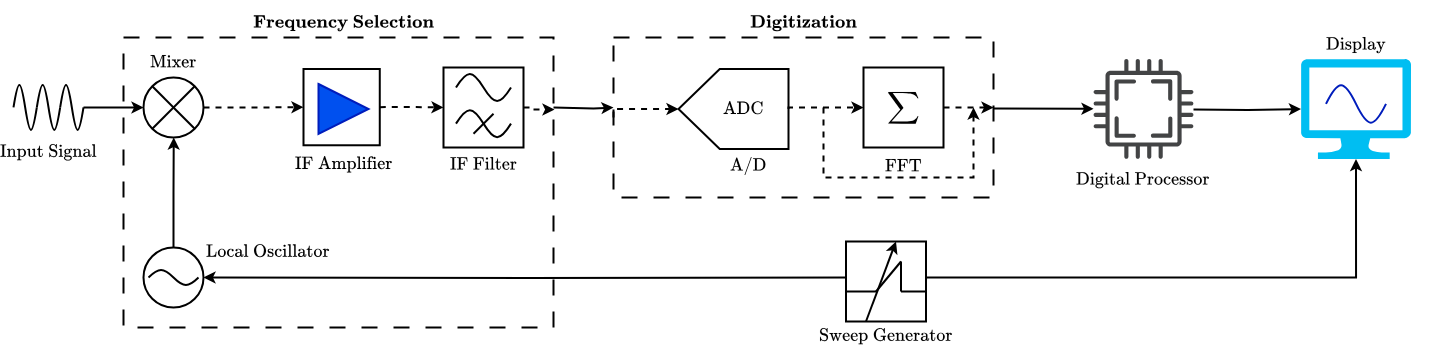
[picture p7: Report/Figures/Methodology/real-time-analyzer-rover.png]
		
		\caption{Vector analyzer block diagram showing digitization of the \acrshort{if} frequency.}
	\end{figure}

	Examples of modern real-time analyzers include:
	
	\begin{itemize}
		\item 
		Tektronix RSA2208A which can scan input signals with frequencies of up to $\SI{8}{\giga\hertz}$.
		\item 
		Rohde \& Schwarz FSP13 which operates within a $\SI{9}{\giga\hertz}$ to $\SI{30}{\giga\hertz}$ \acrshort{rbw}.
		\item
		Agilent E4445A which offer frequency analysis up to $\SI{13.2}{\giga\hertz}$.
		\item 
		FieldFox RTSA which covers $\SI{5}{\kilo\hertz}$ up to $\SI{50}{\giga\hertz}$.
	\end{itemize}

	In modern \acrshort{rtsa}s, \acrshort{if} analog output is transferred to the \acrshort{adc} through an anti-aliasing filter before being stored in memory \cite{tektronixRSA2208A}. This is in contrast to older heterodyne \acrshort{sa}s such as the HP141T which takes the \acrshort{if} output through a video filter is essentially an averaging low-pass filter which smooths the \acrshort{if} output and reduces the effects of internal noise before the signal is channelled to the display \cite{rauscher2007}. HP141T video filters may select $\SI{10}{\hertz}$, $\SI{100}{\hertz}$, $\SI{10}{\kilo\hertz}$ or OFF section of the low-pass filter for the detected video. 
	
	The output of the the HP141T video filter is transmitted to the vertical deflection of the \acrshort{crt} display \cite{HPsiganalyzers}. For the horizontal deflection of the electron beam in the \acrshort{crt} display, a sawtooth signal from the sweep generator governs the horizontal scaling of the output frequency as electrons impinge on the phosphorescent screen. Modern \acrshort{sa}s retrieve data from memory through high speed data lines to display information about the digital signal from the \acrshort{adc}. Digital display technologies include:
	
	\begin{itemize}
		\item 
		\acrshort{lcd} - most commonly used digital display which represents signal data with a sharp image and has low power consumption
		\item 
		\acrshort{oled} - typically used in high performance \acrshort{sa}s for displaying color coded spectrograms
		\item 
		\acrshort{tft} - offer good visual quality and response time for sharper imagery when analyzing high frequency signals.
	\end{itemize}

	Displays in modern \acrshort{sa} architectures offer more options for displaying frequency domain data. This is enabled by the processor, which is typically hosted on microcontroller board with high clock speed for performing digital signal processing algorithms. For example, \acrshort{rtsa}s display the spectrogram as a color coded function of the amplitude of the signal \cite{al2013}. In addition, digital displays generally consume less physical space compared to \acrshort{crt} displays with the same screen dimensions. This has allowed spectrum analyzers to become smaller as they entire system can fit into smaller packaging. For example, the FieldFox is an hand-held \acrshort{rtsa} which despite its size, offers improved performance over the HP141T.
	
	The comparison table in \ref{tab:comparing-old-to-modern} below summarizes the differences between the HP141T analyzer (equipped with the 8555A and 8552B plug-ins) and modern \acrshort{rtsa}s.
	
	 \begin{table}[ht!]
	 	\centering
	 	\begin{tabular}{|m{8em}|m{15em}|m{15em}|}
	 		\hline
	 		\textbf{Feature}	& \textbf{HP141T}	& \textbf{Real-Time Spectrum Analyzer}\\
	 		\hline
	 		Operation &	Heterodyne	&	\acrshort{fft}-based real-time processing\\
	 		\hline
	 		Frequency Range &	$\SI{10}{\giga\hertz}$	- $\SI{40}{\giga\hertz}$	&	DC to $\SI{54}{\giga\hertz}$\\
	 		\hline
	 		Scan Speed &	$\SI{0.1}{\milli\second}/\text{div}$ - $\SI{10}{\second}/\text{div}$	&		Real-time GHz bandwidth capture with no losses\\
	 		\hline
	 		Dynamic Range	&	High but limited by analog filters	& Very high due to digital signal processing\\
	 		\hline
	 		Resolution Bandwidth	&	Adjustable limited by analog filters	&	As low as $\SI{1}{\hertz}$\\
	 		\hline
	 		Real-time Capture	&	No. Displays active signals and struggles with pulsed signals &	Yes. Captures transient and pulsed signals with ease\\
	 		\hline
	 		Signal Processing	&	Analog signal processing with IF filters and logarithmic amplifiers	& Digital signal processing from \acrshort{adc}-sampled signal\\
	 		\hline
	 		FFT Capability	&	- &	Built-in FFT \\
	 		\hline
	 		Display Type	&	\acrshort{crt}	&	\acrshort{lcd}/\acrshort{oled}/\acrshort{tft}\\
	 		\hline
	 		Trace Storage	&	No memory. &	Digital data storage\\
	 		\hline
	 		Connectivity	&	None &	\acrshort{usb}, Wi-Fi, Bluetooth, \acrshort{ble}\\
	 		\hline
	 		Size \& Portability	&	Large and mountable on a rack &	Compact and portable\\
	 		\hline
	 		Settings \& Configuration	&	Manual tuning and calibration	&	Automated measurements, presets, user-friendly\\
	 		\hline
	 	\end{tabular}
 		\caption{Comparing the features of the HP141T system to the modern \acrshort{rtsa}s.}
 		\label{tab:comparing-old-to-modern}
	 \end{table}
	
	Table \ref{tab:comparing-old-to-modern} shows that \acrshort{rtsa}s also have connectivity abilities. For example, data can be transferred serially from on-board memory to an external device through the \acrshort{usb} transfer protocol or through the \acrshort{ble} transfer protocol. 
	
	Features shown in the comparison formulated the modernization criteria to give context to the user requirement specification. Following sections expand on the features which can provide the functionality for associated requirements. 
	
	\subsection{Data Acquisition in Digitizing the HP141T}
	
	As seen in the previous section, a primary criteria for modernizing HP141T is the translation of continuous analog input signals from the time domain to a digital signal that can be assessed using a digital processor such as a single-board computer, \acrshort{fpga}, or microcontroller. Selecting the point at which the conversion occurs in the pipeline of the HP141T super-heterodyne system plays a crucial role in the performance of the modernized system. The following project aimed to fulfil the signal conversion criteria by sampling the input signal at the intermediate frequency in a similar manner to the technique implemented by a modern \acrshort{rtsa} and vector analyzers. In addition, user requirement UR01 states that the system needs to sample 801 points which is a standard for modern signal analyzers.
	
	The following section reviews the user requirements to inform decisions about the data acquisition subsystem of the digitized HP141T subsystem. One of the most crucial parts in the design of the data acquisition subsystem is the selection of the \acrshort{adc} which samples signals and transmits them to the digital processor to store or manipulate signals in real-time. The section describes the limitations of this central part of the system and proposes solutions that can be implemented to fulfil the user requirements.
			
	\subsubsection{\acrshort{adc} Constraints}
	
	Table \ref{tab:adc-constraints} shows constraints that influence the selection of the \acrshort{adc} and a solution for circumventing the limitation. For example, the operating voltage range of the \acrshort{adc} is a constraint which can be circumvented by including a signal conditioning circuit.
	
	\begin{table}[!ht]
		\centering
		\begin{tabular}{|m{8em}|m{15em}|m{15em}|}
			\hline
			\textbf{Constraint}	& \textbf{Problem}	& \textbf{Solution}\\
			\hline
			Operating Voltage	& Limited input voltage range of $\SI{0}{\volt}$ to $\SI{3.3}{\volt}$ or $\SI{5.0}{\volt}$. The HP141T produces incompatible auxiliary output voltages	& Signal conditioning circuit for scaling and shifting signals for compatibility with \acrshort{adc} operating voltages\\
			\hline
			Sample Rate			& Required minimum of 801 points & Select an \acrshort{adc} with a high sampling rate (at 1 \acrshort{msps}) \\
			\hline
			Resolution			& Higher resolution is required for finer amplitude accuracy	& Use an \acrshort{adc} with a minimum resolution of 16-bits\\
			\hline
			Number of Channels	& The HP141T has 3 auxiliary outputs that are related to the frequency vs amplitude plot 	& Use an \acrshort{adc} with at least 3 channels\\
			\hline
			Latency				& High latency can introduce delays in rendering signal data in real-time	& Choose an \acrshort{adc} with \acrshort{spi} for low latency\\
			\hline
			\acrshort{snr}	& \acrshort{adc} with a low \acrshort{snr} are more susceptible to noise and fluctuations in the amplitude 	&	Use an \acrshort{adc} with a high \acrshort{snr}\\
			\hline
		\end{tabular}
		\label{tab:adc-constraints}
		\caption{\acrshort{adc} selection constraints and solutions.}
	\end{table}

	\subsubsection{Conditioning HP141T Output Voltages to Match the \acrshort{adc} Operating Voltages}
	
	To satisfy the modernization requirement, at least three \acrshort{adc} channels are required to sample the three auxiliary analog output signals from the HP141T system that are shown in Table \ref{tab:hp141t-output-voltages} below.
	
	\begin{table}[!ht]
		\centering
		\begin{tabular}{|m{5em}|m{8em}|m{25em}|}
			\hline
			\textbf{Name} & \textbf{Range} & \textbf{Description}\\
			\hline
			 Pen-Lift	&$\SI{0}{\volt}$ to $\SI{14}{\volt}$ & Triggers the \acrshort{crt} display. The pen-lift output is $\SI{0}{\volt}$ during scanning\\
			\hline
			Vertical Output	& $\SI{0}{\volt}$ to -$\SI{0.8}{\volt}$	& Detected video output proportional to the vertical deflection on the \acrshort{crt}, corresponding to the amplitude of the signal in the frequency domain. Voltage range is scaled for full vertical deflection of the electron beam in 8 divisions of the \acrshort{crt} display \\
			\hline
			 Horizontal Output	& -$\SI{5}{\volt}$ to $\SI{5}{\volt}$ & Sawtooth signal for representing scaling frequency across 10 divisions of the horizontal deflection on the \acrshort{crt} display. The HP141T uses this output to control the trace of the spectrum across the screen. \\
			\hline
		\end{tabular}
		\label{tab:hp141t-output-voltages}
		\caption{Auxiliary voltages of the HP141T that must be sampled to digitize the system.}
	\end{table}

	Since the operating voltage of most \acrshort{adc}s is in the range between $\SI{0}{\volt}$ and $\SI{3.3}{\volt}$ or $\pm\SI{5}{\volt}$, the auxiliary outputs listed in table \ref{tab:hp141t-output-voltages} need to be scaled and shift to be within the operating voltage range. To scale the signal, an op-amp based circuit with appropriate gain $A$ can be used between the auxiliary outputs of the HP141T and the input channels of the \acrshort{adc}. To shift the output voltages, a logic level-shifter can be used to translate the signals to be within the operating voltage domain. 

	\subsubsection{Sampling Limitations in the Data Acquisition and Data Processing Subsystems}
		
	Among the constraints in the selection of the \acrshort{adc} is the requirement of the data acquisition subsystem to sample 801 points. Given that the 8552B has 16 internal scan rates from $\SI{0.1}{\milli\second}/\text{div}$ to $\SI{10}{\second}/\text{div}$ in a 1, 2, 5 sequence and given that the data acquisition subsystem needs to store 801 points per scan, the fastest scan rate, corresponding to $\SI{0.1}{\milli\second}/\text{div}$, can be achieved using an \acrshort{adc} with a sampling rate of 
	\begin{align}
		\frac{801\text{samples}}{\SI{0.1}{\milli\second}}	& = 8.01~\textbf{\acrshort{msps}}\nonumber
	\end{align}
	Similarly, for the slowest scan rate corresponding to $\SI{10}{\second}/\text{div}$, the required minimum sampling rate of the \acrshort{adc} is 80.1 \acrshort{sps}.
	
	In addition to the sample rate of the \acrshort{adc}, the design must take several factors into account regarding the integration of the \acrshort{adc} with a digital processor such as a \acrshort{sbc}, \acrshort{mcu}, or \acrshort{fpga}. Table \ref{tab:digital-processor-considerations} shows the considerations that need to be made in selecting a digital processor that is compatible with the operation of the \acrshort{adc} and high sampling rate.
	
	\begin{table}[!ht]
		\centering
		\begin{tabular}{|m{5em}|m{15em}|m{20em}|}
			\hline
			\textbf{Digital Processor Type}	& \textbf{Consideration}	&	\textbf{Feature}\\
			\hline
			\multirow{3}{*}{\acrshort{mcu}}	& Communication Interface &	Supports $\text{I}^2\text{C}$ and \acrshort{spi} \\
			\cline{2-3}
			& Data Transfer Rate & Up to hundreds of $\si{\mega\hertz}$\\
			\cline{2-3}
			& Synchronization and Timing &	Can use interrupts and \acrshort{fifo} buffers \\
			\hline
			\multirow{3}*{\acrshort{sbc}}	& Communication interface	& Supports $\text{I}^2\text{C}$ and \acrshort{spi}	\\
			\cline{2-3}
			& Data Transfer Rate & Suited for low sampling rates\\
			\cline{2-3}
			& Synchronization and Timing & Requires buffering and introduces operating system relating delays\\ 
			\hline
			\multirow{3}*{\acrshort{fpga}}	&	Communication Interface & Supports \acrshort{spi} and high-speed parallel interfaces\\
			\cline{2-3}
			& Data Transfer Rate & Can handle sampling rates at hundreds of $\si{\mega\hertz}$ to $\si{\giga\hertz}$ speeds.\\
			\cline{2-3}
			& Synchronization and Timing &	Uses parallel data pipelines suitable for high-speed sampling rates for real-time spectral analysis applications.\\
			\hline
		\end{tabular}
		\caption{Digital processor selection based on \acrshort{adc} interface considerations.}
		\label{tab:digital-processor-considerations}
	\end{table}
		 
	Table \ref{tab:digital-processor-considerations} indicates that to fulfil the requirement for sampling 801 points per scan, the design that can deliver the highest performance in real-time data acquisition should include an \acrshort{adc} which can perform 8.01 \acrshort{msps} and a \acrshort{fpga} with multiple pipelines for storing and processing rapidly sampled data in parallel. Alternatively, a heterogeneous digital processor can be implemented using a suitable combination of the available options listed in the table. For example, a Xilinx Artix-7 \acrshort{fpga} can be used for high-speed data acquisition while a Raspberry Pi \acrshort{sbc} is used to process and display data. \acrshort{mcu}s can also be daisy-chained to perform different tasks in the data acquisition subsystem. 
	
	\subsubsection{Further Design Considerations in Digital Processor Selection}
	
	While \acrshort{fpga}s offer superior speeds in data acquisition and processing, one of the shortcomings of selecting it as the primary digital processor is that the overall development time is typically longer than the design time for \acrshort{mcu}s and \acrshort{sbc}s. This is because \acrshort{fpga} development has a structured design flow which includes details of the register-transfer level (\acrshort{rtl}) using a hardware description language (\acrshort{hdl}), validation, synthesis and implementation. Although tools like AMD Vivado exist to significantly reduce \acrshort{fpga} development times, the other available options offer significantly shorter development times. 
	
	Table \ref{tab:digital-processor-comparison} gives a comparison between the available digital processor options to highlight the most suitable option for fulfilling the requirements of this project. 
	
	\begin{table}[ht!]
		\centering
		\label{tab:digital-processor-comparison}
		\begin{tabular}{|m{8em}|m{10em}|m{10em}|m{10em}|}
			\hline
			\textbf{Design Aspect}	&	\textbf{\acrshort{mcu}}	&	\textbf{\acrshort{sbc}}	&	\textbf{\acrshort{fpga}}\\
			\hline
			Development Time	&	Short	&	Moderate	& 	Long\\
			\hline
			Processing Speed	& 	Medium	&	Moderate to High	& 	High\\
			\hline
			Programming Language	& C/C++ &	Python or C/C++	 & VHDL or Verilog\\
			\hline
			On-board Memory and \acrshort{ram}	& Very Low & High	& Low\\
			\hline
			Power consumption	& Low	& High	& Moderate to High\\
			\hline
			Scalability		& High	& Moderate	& High \\
			\hline
			Cost	& Low	& Moderate to High	& High\\
			\hline	
		\end{tabular}
		\caption{A structure comparison of the available digital processor options.}
	\end{table}

	The different benefits of choosing a certain digital processor can be deduced from Table \ref{tab:digital-processor-considerations} and \ref{tab:digital-processor-comparison}. Other considerations need to made regarding the memory capacity of the chosen processor, however, the primary objective is to satisfy UR06 which requires the data acquisition subsystem to be capable of storing and recalling traces. Due to the high sampling rate, the device must have a sufficient large memory capacity for storing signal frequency and amplitude related information at high-speeds. Specifically, given that a minimum sampling rate of 8.01 \acrshort{msps} is required and supposing that the resolution of the \acrshort{adc} is 16-bit, the device must be able to store
	\begin{align}
		8.01 \text{MSPS} \times \SI{16}{\bit} & = \SI{128160000}{\bit\per\second}\nonumber
	\end{align}
	In other words, the device must be able to store $\SI{16.02}{\mega\byte\per\second}$, which equates to approximately $\SI{1}{\giga\byte}$ per minutes. Thus, the selected digital processor must include efficient memory management algorithms to ensure that data is not lost or corrupted. The table indicates that the \acrshort{mcu} has the most limited capability with respect to memory. This is because \acrshort{mcu}s typically have few KB to MB of \acrshort{ram} and require external memory. Similarly, \acrshort{fpga}s offer limited memory capabilities since they typically use a small embedded \acrshort{ram} and require external memory for large data buffers. 
	
	In summary, the \acrshort{mcu} is most suitable for its low cost, low power consumption, good real-time capabilities and short development time. However, the \acrshort{mcu} is only suitable for moderate-speed sampling, which is not ideal for the high sampling rates that are needed to fulfil the requirements. While \acrshort{sbc}s offer intermediate performs and features that combine the moderate capabilities of \acrshort{mcu}s and \acrshort{fpga}s, their primary shortcoming is poor real-time capabilities due to \acrshort{os} delays and overall low latency. Finally, the best option for this application is the \acrshort{fpga} due to its ability to perform real-time high-speed data processing and \acrshort{adc} synchronization, however, the biggest shortcomings are the development time and high cost. 
	
	Due to time constraints and low availability of the STM32H723ZG development board, inquiries into alternative devices were taken into consideration to ensure that data can be sampled in the case where the STM32H723ZG is not available. The Field-Fox is a spectrum analyzer that can be used to acquire amplitude vs frequency data directly, similar to the HP141T system. However, to extract amplitude vs frequency plot data in the time domain corresponding to the time series outputs of the HP141T \acrshort{sa}, a digital oscilloscope can be used. This includes devices such as the R\&S RTC1000 oscilloscope Rhode \& Schwarz and Keysight HD304MSO with 4 analog channels. Most modern digital oscilloscopes can measure various parameters like voltage, frequency and phase, and the ability to interface with a personal computer. Sizes of these oscilloscopes can range from small and portable to very large devices that are typically used in lab settings. Smaller, hand-held devices include products from Fluke, Pico Technologies, and Tektronix. 
	
	These oscilloscopes can be used as alternative sampling devices, given that the device is capable of storing data in a readable format. Digital oscilloscopes typically have an associated desktop software which can display samples of channels linked to input connects. However, given that the aim of the project is to digitize the HP141T \acrshort{sa} in accordance with the tabulated requirements, the \acrshort{gui} that comes with an oscilloscope cannot be used as the graphical interface of the design because it may not necessary fulfil the requirements. Instead, the oscilloscopes and accompanying software can be used as alternative sampling devices in the data acquisition subsystem, or for taking measurements during the testing and verification phase of the design process. 
	
	\subsection{Design Considerations in Satisfying Display Requirements}
	
	The choice of display depends on the selected processor type. The display hardware must satisfy multiple user requirements including UR03, UR07 and UR09 which are related to resolution, functionality and power. Further considerations have to be made for the display to satisfy requirements relating to the user interface (\acrshort{ui}). The following section breaks down these requirements separately to evaluate the design choices that need to be made in modernizing the HP141T display.

	\subsubsection{Display Hardware Considerations for a \acrshort{mcu}-Based System}
	
	Table \ref{tab:mcu-display-options} assimilates the design considerations for a \acrshort{mcu}-based system. Overall, the design needs to consider factors such as clock and I/O speed, memory, power consumption and the display interface.
	
	\begin{table}[ht!]
		\centering
		\begin{tabular}{|m{5em}|m{10em}|m{24em}|}
			\hline
			\textbf{Key Consideration}	&	\textbf{Aspects}	& \textbf{Description}\\
			\hline
			\multirow{3}{*}{Processor}	& Clock Speed	& Clock speed of at least $\SI{100}{\mega\hertz}$ for rendering 801 points per scan to the display\\
			\cline{2-3}
			&	Architecture &	A 32-bit ARM Cortex-M series \acrshort{mcu} is preferred for good balance between power efficiency and speed\\
			\cline{2-3}
			&	I/O Speed & \acrshort{adc} waveform samples need to be rendered at high speeds. \acrshort{spi} is recommended for improving latency\\
			\hline
			\multirow{2}{*}{Memory}	& 	\acrshort{ram}	& At least $\SI{128}{\kilo\byte}$ of \acrshort{ram} required for real-time display rendering\\
			\cline{2-3}
			&	Flash Memory	&	Required for storing firmware and display configurations which need to be loaded during power-up.\\
			\hline
			\multirow{2}{*}{Interface}	&	Compatibility	& Should support the same communication interfaces as the display screen.\\
			\cline{2-3}
			&	Resources &	Modern displays include internal frame buffers which can reduce the effect of memory and data transfer bottlenecks.\\
			\hline
			\multirow{2}{*}{Power}	&	Compatibility & System must be powered by a single wall wart power supply.\\
			\cline{2-3}
			&	Efficiency	&	Low-power and standby modes can reduce energy consumption when the display is idle.\\
			\hline
		\end{tabular}
		\caption{Key considerations for the display subsystem for a \acrshort{mcu}-based system.}
		\label{tab:mcu-display-options}
	\end{table}
	
	\subsubsection{Display Hardware Considerations for a \acrshort{sbc}-Based System}
	
	If the chosen digital processor is a single-board computer such as the Raspberry Pi 4B, similar considerations need to be made regarding its compatibility of the display unit. Differences arise from the hardware capabilities that the \acrshort{sbc} offers. Table \ref{tab:sbc-display-options} summarizes the design considerations that need to be made for the interface between \acrshort{sbc} and the display unit.
	
	\begin{table}[ht!]
		\centering
		\begin{tabular}{|m{5em}|m{10em}|m{24em}|}
			\hline
			\textbf{Key Consideration}	&	\textbf{Aspects}	& \textbf{Description}\\
			\hline
			\multirow{2}{*}{Resolution} 
			& 1080p at 60Hz & Recommended for smooth spectrum rendering; higher resolutions. \\
			\cline{2-3}
			& HDMI 2.0 & A high-speed \acrshort{hdmi} 2.0-compatible display is required for the best display quality. \\
			\hline
			
			\multirow{3}{*}{\acrshort{hdmi}} 
			& \acrshort{hdmi} Version Support & Older monitors may only support HDMI 1.2, which could limit resolution and refresh rates \\
			\cline{2-3}
			& Data Handling & Improper extended display identification data detection may require manual configuration \\
			\cline{2-3}
			& Adapter	& Micro-\acrshort{hdmi} to \acrshort{hdmi} adapters are required. Faulty adapters may introduce noise\\
			\hline
			
			\multirow{3}{*}{Touch} 
			& Touch Display & Dedicated \acrshort{sbc} touchscreens can be used \\
			\cline{2-3}
			& \acrshort{dsi} & Raspberry Pi touchscreen connect via the \acrshort{dsi} (Display Serial Interface) without required \acrshort{hdmi}\\
			\cline{2-3}
			& Power & Dedicated screen can be powered by the \acrshort{sbc}\\
			\hline
			
			\multirow{2}{*}{Monitor} 
			& Compatibility & Selected display must support the required resolution and refresh rate for clear visualization of digitized spectra. \\
			\cline{2-3}
			& Over-scanning & Display adjustments may be required for screens that crop spectrum visualizations. \\
			\hline
						
			\multirow{2}{*}{Software} 
			& OS Support & Dedicated \acrshort{os} recommended for compatibility with built-in display drivers and utilities. \\
			\cline{2-3}
			& Settings & Used to adjust display resolution, rotation, and other settings for the most suitable spectrum visualization. \\
			\hline
		\end{tabular}
		\caption{Display considerations for screen integration with a \acrshort{sbc}-based system.}
		\label{tab:sbc-display-options}
	\end{table}
	
	\subsubsection{Display Hardware Considerations for a \acrshort{fpga}-Based System}
	
	Although \acrshort{fpga}s offer the best performance with respect to sampling rates and data processing speeds, they are not as suitable for processing display data compared to \acrshort{sbc}s. However, the real-time capabilities of the \acrshort{fpga}-based system can provide a seamless user experience by rendering spectrum displays at a high frame rate. Table \ref{tab:fpga-display-options} lists the design considerations for the display of a \acrshort{fpga}-based system.
	
	\begin{table}[ht!]
		\centering
		\begin{tabular}{|m{8em}|m{10em}|m{22em}|}
			\hline
			\textbf{Key Consideration} & \textbf{Aspects} & \textbf{Description} \\
			\hline
			\multirow{3}{*}{Video Output} 
			& \acrshort{hdmi} Support & Different FPGAs feature built-in \acrshort{hdmi}, \acrshort{dvi} transmitters or external serializer chips. The chosen FPGA must support high-speed video output \\
			\cline{2-3}
			& Parallel & For parallel \acrshort{rgb} inputs, the FPGA must generate compatible timing signals for proper synchronization \\
			\cline{2-3}
			& Buffering & Additional external memory may be required for storing video frames before display \\
			\hline
			
			\multirow{2}{*}{Synchronization} 
			& Pixel Clock & Display’s resolution and refresh rate requirements must be compatible with a stable \acrshort{fpga} pixel clock \\
			\cline{2-3}
			& Fabric Speed & Spectrum updates can be rendered rapidly using the high-speed fabric which ensure low-latency \\
			\hline
			
			\multirow{3}{*}{Interface} 
			& Protocols & The display must be able to interface with the available hardware on the \acrshort{fpga} \\
			\cline{2-3}
			& Controller & Display must be compatible with \acrshort{fpga} IP cores for developing display functionality more easily\\
			\cline{2-3}
			& Resources & Optimization is needed to balance consumption of \acrshort{fpga} logic, memory block and I/O pins by the display unit \\
			\hline
			
			\multirow{2}{*}{Memory} 
			& \acrshort{ram} & External DDR memory may be necessary for extending limited on-chip RAM capacity \\
			\cline{2-3}
			& Storage & Efficient memory management is essential to prevent bottlenecks \\
			\hline
			
			\multirow{2}{*}{Power} 
			& Delivery & Some high-speed video interfaces require additional power regulators\\
			\cline{2-3}
			& Heating & FPGA video processing generates heat which may require cooling to prevent damage to components of the \acrshort{fpga} \\
			\hline
			
			\multirow{2}{*}{Software} 
			& Drivers & Display drivers must be implemented using \acrshort{hdl} or software cores\\
			\cline{2-3}
			& Updates & Updates must occur in real-time and support different display modes \\
			\hline
		\end{tabular}
		\caption{Display considerations for an FPGA-based HP141T modernization system.}
		\label{tab:fpga-display-options}
	\end{table}
	
	\subsubsection{Display User Interface}

	User requirements relating to the aspects of the display that the user can interact with include UR02, UR04, UR05 and UR07. The primary objective of the project is to display a plot of the amplitude vs frequency for the input signal, in real-time. To achieve this objective, spectrum data needs to be organized and easily accessible from \acrshort{ram} or flash memory, depending on the architecture of the system that is centred around the \acrshort{adc} and digital processor. For example, STM microcontrollers have a dedicated \acrshort{lcd}-\acrshort{tft} display controller with a frame buffer that can be located either in on-chip memory or in an external memory, depending on the resolution. Using external memory can increase latency which decreases the real-time performance of the system. 
	
	In addition, data needs to be scaled while considering the effects of windowing, so that all spectrum data can be translated to a grid with 8 divisions of the amplitude, on the vertical axis, and 10 divisions of the frequency, on the horizontal axis. This is also to ensure that the graphical interface resembles the appearance of the \acrshort{crt} display, as shown in Figure \ref{fig:display-section}, is maintained.
	 
	\begin{figure}[ht!]
		\centering
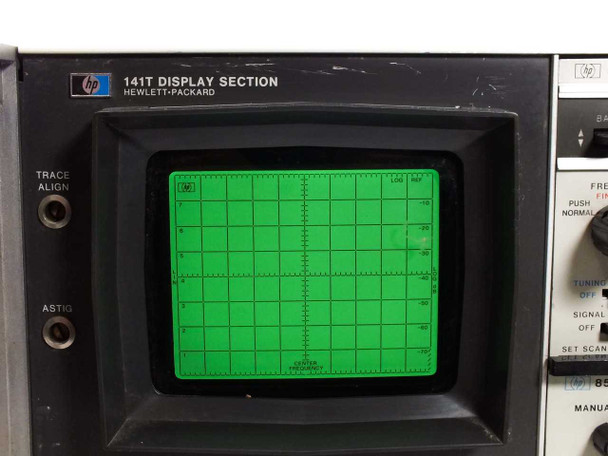
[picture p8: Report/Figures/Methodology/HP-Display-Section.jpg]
		
		\caption{HP141T \acrshort{crt} display section.}
		\label{fig:display-section}
	\end{figure}
	
	Secondary objectives include digitizing the operations that were previously executed by physical knobs such as horizontal and vertical scaling of the waveform. This objective can be  as functions in a program that can be called to perform similar task. The choice of coding language and available development tools for the program that runs the display is a critical part of the \acrshort{ui} subsystem. 
	
	An alternative approach to handling data acquisition and display functions on the same board would be to use a single-board computer for the display. Spectrum data can be retrieved from memory and displayed to the user in a Python, C/C++ or Java program. Knobs can be replaced by programmatic buttons with functions that users can access by touching the screen. This can allow other features such as averaging and displaying maxima and minima to be easily accessible to the user. For this project, \acrshort{ui} must enable users to select between different display modes, including the \acrshort{phm}, \acrshort{avm} and \acrshort{rwm}. The \acrshort{ui} must enable users to switch between these modes seamlessly and allow for back them to return to previous screens using a back button in the program.
	
	Overall, the project aims to adhere to Nielsen's heuristic design principles which includes:
	\begin{enumerate}
		\item
		Match between the system and the HP141T -  the program should use the language and current features of the HP141T that users are familiar with
		\item 
		User control and freedom - the \acrshort{ui} must support undo, redo and exit points
		\item 
		Aesthetics and minimalist design - the most relevant information that must be displayed is related to the frequency plot of the input signals as well as configurations and settings of the data acquisition and digital processing units that give context to the current display
		\item 
		Flexibility and efficiency of use - the \acrshort{ui} interface of the modernized HP141T must be optimized for difference experience levels through suitable shortcuts and frequent actions such as averaging and showing maxima and minima of the input signal.
		\item 
		Help and documentation - documentation of the modernized HP141T display must correspond to current documentations of the entire system and must be easy to read
		\item 
		Error prevention - the \acrshort{ui} must protect users from deleting stored traces and signal information
		\item 
		Visibility - a user must always know what is happening within the program and current state of their actions
		\item 
		Consistency and standards - the appearance of the \acrshort{ui} must follow the conventions of modern spectrum analyzer displays through consistent words, situations and actions.
		\item 
		Help user to recognize, diagnose and recover from errors such as closing windows with information about pulses or signal noise
		\item 
		Recognition rather than recall - minimize users' memory load by making program features that are related to the most accessed signal data easy to access
	\end{enumerate}
	
	\subsection{Equipment for Debugging and Testing}
	
	The following section gives a review of the project requirement which necessitates the development of an HP141T display emulator of the three auxiliary outputs as shown in \ref{tab:hp141t-output-voltages}. Additionally, the section describes software-based simulation tools that can be used in the development for debugging and obtaining an idea about the expected behaviour individual hardware components and overall system.
	
	\subsubsection{Emulating HP141T Auxiliary Outputs}
	
	The sawtooth signal can be generated using a 555-timer circuit which produces a ramp voltage with adjustable frequency to mimic the adjustable scan time, and a fixed peak-to-peak voltage of $\SI{10}{\volt}$ with no \acrshort{dc} offset. This is to ensure that the horizontal sawtooth output range between $-\SI{5}{\volt}$ and $+\SI{5}{\volt}$ is maintained. 
	
	To emulate the vertical output which swings between $\SI{0}{\volt}$ and $-\SI{0.8}{\volt}$, a simple voltage biasing circuit can be built with appropriate resistor values and input voltage. To control this level, a potentiometer can be used to manually adjust the voltage level within that range. Similarly, the pen-lift output can be produced using a biasing circuit with a potentiometer that allows the voltage to swing between $\SI{0}{\volt}$ and $\SI{14}{\volt}$. 
	
	Lastly, the HP141T display emulator circuit needs to interface with the signal conditioning circuit that prepares the signal voltages to match the operating range of the \acrshort{adc}. Therefore, to avoid the development of multiple circuits, the output cables of the display emulator must be the same as the output cables that take the auxiliary outputs from the HP141T to the signal conditioning circuit.
	
	\subsubsection{Software-Based Simulation Tools}
	
	To optimize the selection and configuration of the data acquisition subsystem, \acrshort{adc}s can be simulated in MATLAB using Simulink to understand the behaviour of the sawtooth input from the HP141T or emulating hardware. Additionally, Simulink provides visualizations of the spectrum of the \acrshort{adc} output which can be used to determine the expected values from sampling signals. Simulink also allows users to add impairments to the \acrshort{adc} for introducing a layer of non-linearity that may be seen for signals with frequencies that are close the edges of the \acrshort{rbw} or intermediate frequency. 
	
	Electronic circuits, such as the signal conditioning circuits with op-amps and level-shifters, can be simulated using LTSpice to predict the expected behaviour. Output values from LTSpice simulations can be used to simulate the behaviour of the system using Simulink with MATLAB.
	\clearpage		
	\section{System Design}
	
	Design decisions in formulating the specifications were informed by the requirement review in the previous section. This section aims to give a full description of the system and the interfaces between the different subsystems. The section begins with a visual representation of the system using a block diagram. Following the visual representation of the design, the section includes specifications and concludes with acceptance and integration tests. 
	
	\subsection{Overview System Block Diagram}
	
	The system block diagram shown in Figure \ref{fig:overall-system-block-diagram} below is a graphical overview of the different stages that an RF signal goes through before the amplitude vs frequency graph is displayed. The modernized HP141T maintains the basic analog signal processing functionality performed by the HP8555A \acrshort{rf} section and the HP8552B \acrshort{if} sections. The scope of the proposed design does not involve any changes to the signal processing components of the plug-in sections. However, the Signal Conditioning Subsystem (\acrshort{scs}) prepares the three auxiliary outputs from the HP552B \acrshort{if} section for the Data Acquisition Subsystem (\acrshort{das}) which requires input voltages in the range between $\SI{0}{\volt}$ and $\SI{3.3}{\volt}$. 	
	
	\begin{figure}
	 	\centering
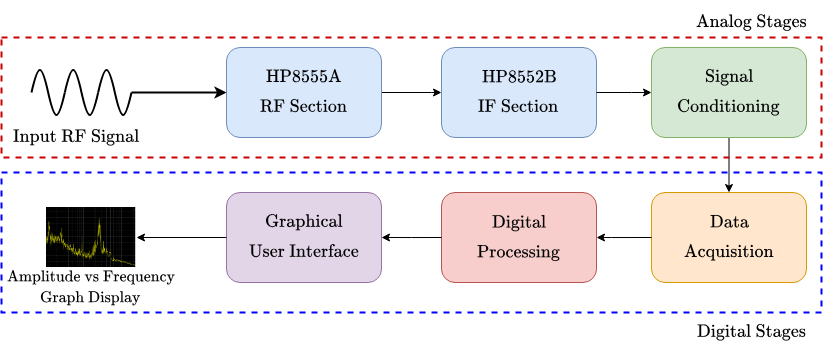
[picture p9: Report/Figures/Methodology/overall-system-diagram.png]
	 	
	 	\caption{Overview system block diagram for the modernized HP141T which employs the HP8555A and HP8552B plug-in sections.}
	 	\label{fig:overall-system-block-diagram}
	 \end{figure}
 
	\acrshort{adc}s in the \acrshort{das} play a primary role in digitizing the HP141T system by converting the conditioned analog signals into digital values which can be processed in the Digital Processing Subsystem (\acrshort{dps}) which enables manipulation of the digital values. This is particularly necessary for averaging and executing other arithmetic operations in order to satisfy the needs of the user. The Graphical User Interface Subsystem (\acrshort{guis}) manages the display and user preferences for displaying the amplitude vs frequency information of the input \acrshort{rf} signal.
		
	Overall, the can be modularized into five primary subsystems, including:
	\begin{enumerate}
		\item 
		HP141T Subsystem
		\item 
		Signal Conditioning (\acrshort{scs})
		\item 
		Data Acquisition (\acrshort{das})
		\item 
		Digital Processing (\acrshort{dps})
		\item 
		Graphical User Inferface (\acrshort{guis})
	\end{enumerate}
	
	Although this project does not involve the redesign of the HP141T subsystem, an HP141T Emulator design is proposed for simulating the outputs of the \acrshort{if} plug-in section. In particular, the emulator produces signals that are similar to the horizontal, vertical and pen lift outputs of the HP8552B plug-in. This implies that the emulator can be considered as a secondary subsystem that can substitute the HP141T subsystem during calibration of the digital section of the proposed design, as illustrated in figure \ref{fig:emulated-system-diagram}. Furthermore, the diagram illustrates that the emulator does not have high frequency input signals like the HP8555A \acrshort{rf} section plug-in. Instead, oscillators and function generator chips are proposed for producing outputs that approximate the auxiliary outputs, as shown in table \ref{tab:hp8552b-output-vals}.
	
	\begin{figure}[ht!]
		\centering
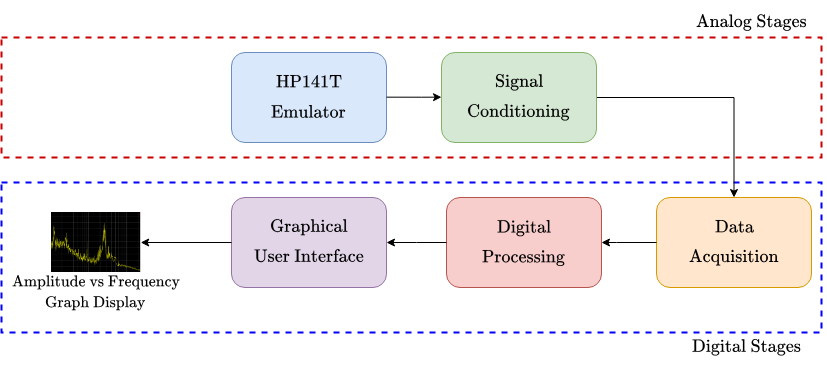
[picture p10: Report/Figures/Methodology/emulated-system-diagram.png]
		
		\caption{Calibration system diagram where the HP141T Emulator is used to configure the primary subsystems such as the \acrshort{scs}, \acrshort{das}, etc.}
		\label{fig:emulated-system-diagram}
	\end{figure}

	All analog stages are executed in \acrshort{pcb}s, and the digital stages are performed by a microcontroller and single-board computer. The following sections detail the specifications of the system modularization and components.

	\subsection{System Modularization}
	
	The system block diagram is expanded as illustrated in figure \ref{fig:system-block-diagram} where the primary components of each of the subsystems are shown. In the diagram, arrows with a solid line illustrate interfaces between subsystems, while arrows with dotted lines describes the flow of analog or digital signals within each subsystem.  
	\begin{figure}
		\centering
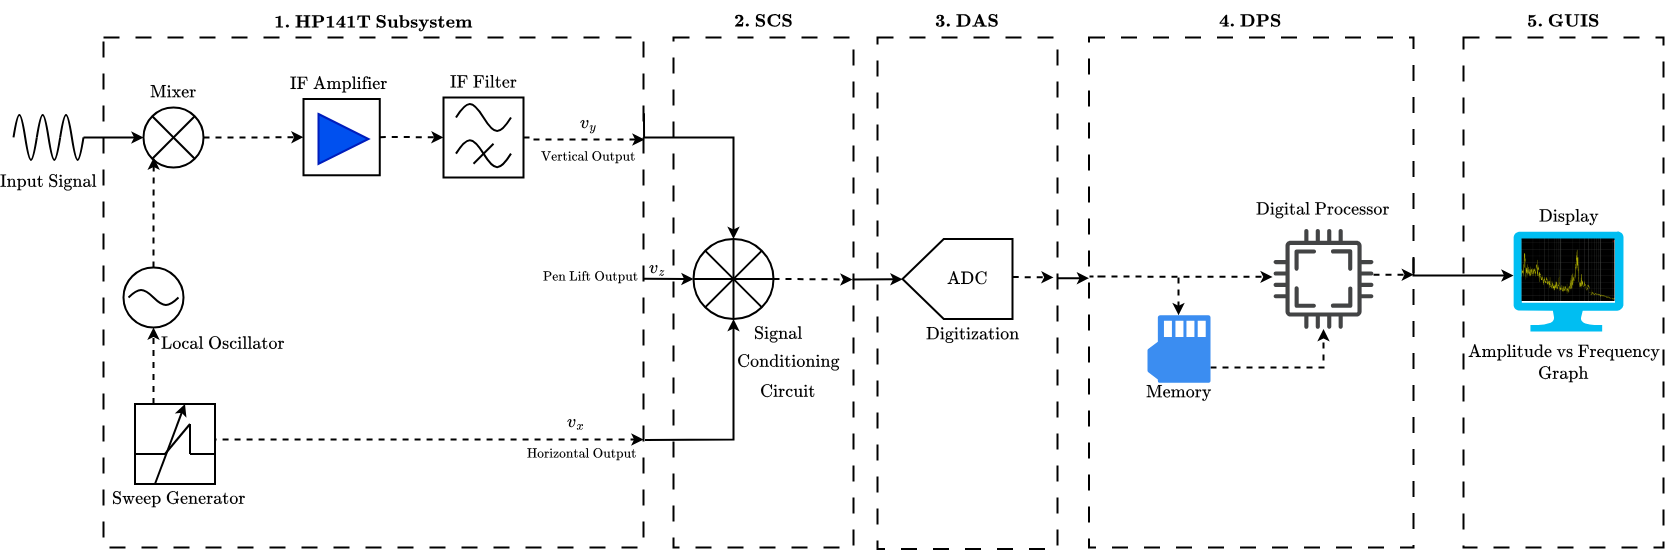
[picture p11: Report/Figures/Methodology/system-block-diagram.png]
		
		\caption{Expansion of the overall system diagram showing the primary components and functions in each subsystem.}
		\label{fig:system-block-diagram}
	\end{figure}

	\begin{table}[ht!]
		\centering
		\label{tab:subsystem-components}
		\begin{tabular}{|m{18em}|m{15em}|m{8em}|}
			\hline
			\textbf{Subsystem}	&\textbf{Component}	& \textbf{Signal Type}\\
			\hline
			\multirow{2}{*}{\textbf{HP141T Subsystem}}	& HP8555A	& Analog\\
			\cline{2-3}
														& HP8552B	& Analog\\
			\hline
			\multirow{3}{*}{\textbf{HP141T Emulator}}	& Vertical Output Simulator	& Analog\\
			\cline{2-3}
														& Horizontal Output Simulator & Analog\\
			\cline{2-3}
														& Pen Lift Output Simulator	& Analog\\
			\hline
			\multirow{3}{*}{\textbf{\acrlong{scs}}}	& Op-amp based vertical output conditioning circuit													& Analog\\
			\cline{2-3}
														& Op-amp based horizontal output conditioning circuit		& Analog\\
			\cline{2-3}
														& Op-amp based pen-lift output conditioning circuit 	& Analog\\
			\hline
			\multirow{3}{*}{\textbf{\acrlong{das}}}	& \acrshort{adc} & Analog/Digital\\
			\cline{2-3}
														& \acrshort{mcu} & Digital\\
			\cline{2-3}
														& Storage Device & Digital\\
			\hline
			\multirow{2}{*}{\textbf{\acrlong{dps}}}	& \acrshort{mcu} & Digital\\
			\cline{2-3}
														& \acrshort{sbc} & Digital\\
			\hline
			\multirow{3}{*}{\textbf{\acrlong{guis}}}	& \acrshort{sbc} & Digital\\
			\cline{2-3}
														& LCD Touch Screen & Digital/Analog\\
			\cline{2-3}
														& Software library & Digital \\
			\hline
		\end{tabular}
		\caption{Showing components in each subsystem and the type of signals that are processed by each unit.}
	\end{table}

	Figure \ref{fig:system-block-diagram} is accompanied by table \ref{tab:subsystem-components} showing subsystem components in more detail. The table also details the components of the HP141T Emulator subsystem. Signal types are noted in table \ref{tab:subsystem-components} because a significant part of the system behaviour can be attributed to the interchange between continuous or discrete values. 
	
	\subsubsection{HP141T Subsystem Specifications}
	
	Table \ref{tab:hp8552b-output-vals} shows the expected outputs collected from the technical manual of the plug-in which also details the expected frequency range. 
	\begin{table}[ht!]
		\centering
		\label{tab:hp8552b-output-vals}
		\begin{tabular}{|c|c|c|c|}
			\hline
			\textbf{Output}	& \textbf{Symbol}& \textbf{Voltage Range}	& \textbf{Bandwidth} \\
			\hline
			Horizontal & $\texttt{V}_\texttt{x}$	& $-\SI{5.0}{\volt}$ to $\SI{+5.0}{\volt}$	& $\SI{0.005}{\hertz}$ to $\SI{500}{\hertz}$\\
			\hline
			Vertical & $\texttt{V}_\texttt{y}$	& $-\SI{0.8}{\volt}$ to $\SI{0}{\volt}$	& $\SI{10}{\hertz}$ to $\SI{300}{\kilo\hertz}$\\
			\hline
			Pen Lift & $\texttt{V}_\texttt{z}$  & $\SI{0}{\volt}$ to $\SI{14}{\volt}$  & $\SI{0}{\hertz}$\\
			\hline
		\end{tabular}
		\caption{Characteristic values of the HP8552B \acrshort{if} plug-in section's analog output signals \cite{hp8552b}.}
	\end{table}

	Table \ref{tab:hp8552b-amplitude-specs} shows the amplitude specifications of the HP8552B plug-in section. 
	
	\begin{table}[ht!]
		\centering
		\label{tab:hp8552b-amplitude-specs}
		\begin{tabular}{|m{8em}|m{10em}|m{8em}|m{8em}|}
			\hline
			\textbf{Operation Mode}	& \textbf{Amplitude Calibration Range} & \textbf{Amplitude per Division} ($\si{\decibel}$/div)	& \textbf{Display Range} ($\si{\decibel}$)\\
			\hline
			Logarithmic & $-\SI{130}{\decibel}\text{m}$	to $+\SI{10}{\decibel}\text{m}$ & 10 & 70	\\
			\hline
			Linear & $-\SI{23}{\decibel\volt}$	to $+\SI{117}{\decibel\volt}$ 	& 10 & 70\\
			\hline
		\end{tabular}
		\caption{Amplitude specifications of HP8552B plug-in section \cite{hp8552b}.}
	\end{table}
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

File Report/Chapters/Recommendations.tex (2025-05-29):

% ----------------------------------------------------
% Recommendations
% ----------------------------------------------------
\documentclass[class=report,11pt,crop=false]{standalone}
\input{../Style/ChapterStyle.tex}
\input{../FrontMatter/Glossary.tex}
\begin{document}
% ----------------------------------------------------
\chapter{Recommendations \label{ch:recommendations}}
\epigraph{It is for us the living, rather, to be dedicated here to the unfinished work which they who fought here have thus far so nobly advanced.}%
    {\emph{---Abraham Lincoln}}
\vspace{0.5cm}
% ----------------------------------------------------
\section{Subsystem Recommendations}

\subsection{Recommendations for the HP141T System Tests}

The unit tests for verifying the operation of the HP141T system should be performed with the access to the actual device to confirm the results obtained using the Siglent SDG1010.

\subsection{Recommendations for the HP141T Emulator}

The system should use the E24 series of resistances to ensure that the design follows the recommended circuit structures in the datasheet of the XR2206 function generator.

Isolated tests should be performed for each chip on a breadboard to ensure that they are functioning as exepected.
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

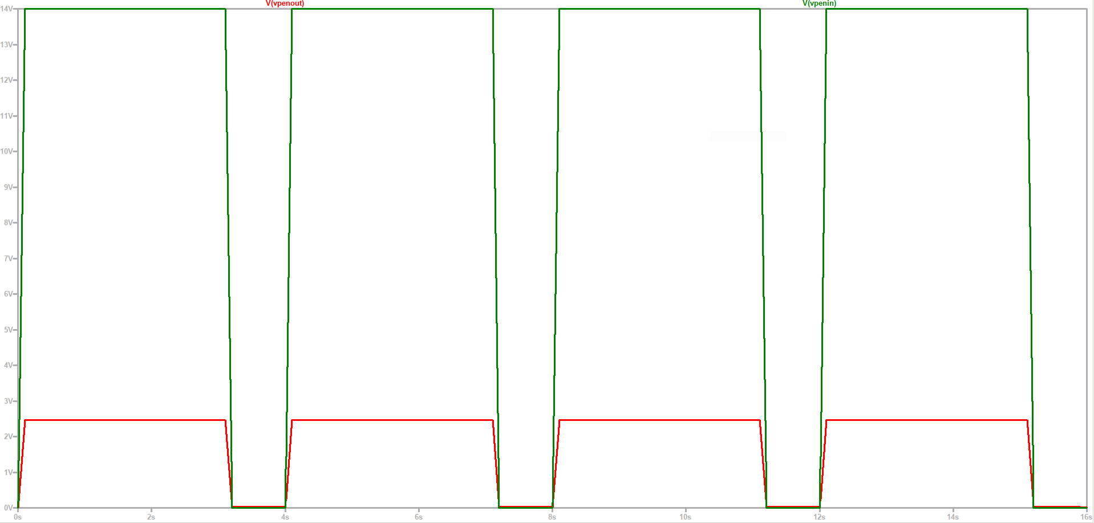
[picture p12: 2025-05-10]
Report/Figures/Methodology/sig-cond-plsc-sim-output-14V.png

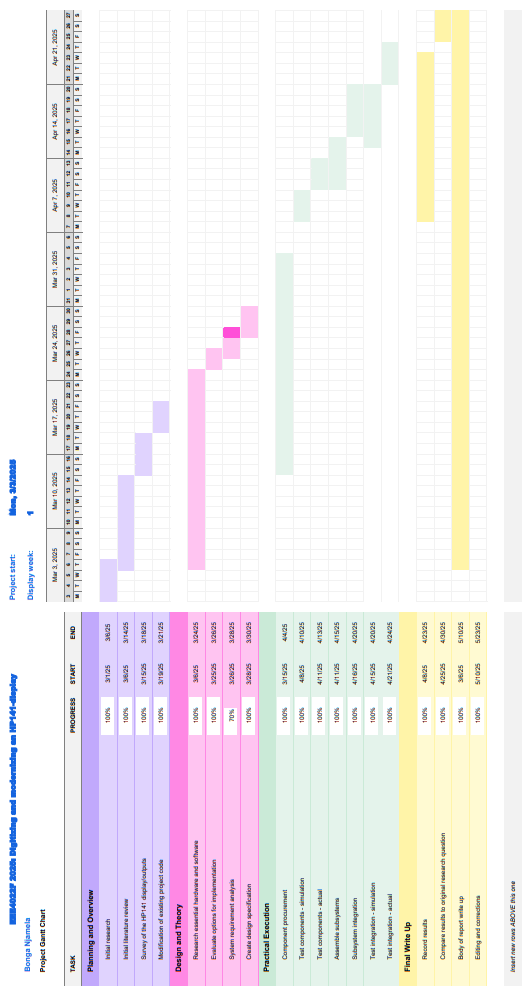
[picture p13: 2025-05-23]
Report/Figures/Appendices/gantt-chart.png

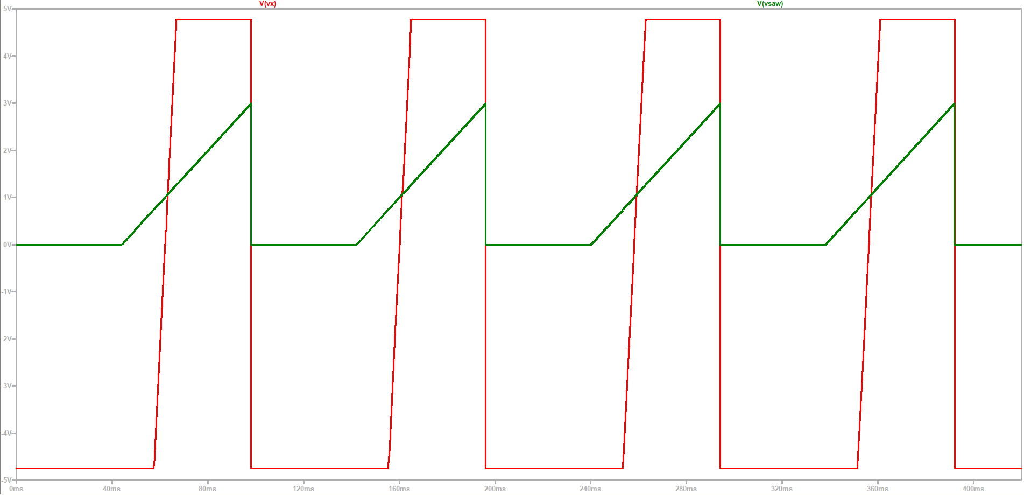
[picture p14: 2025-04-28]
Report/Figures/Methodology/emulator-sawtooth-output-1.png

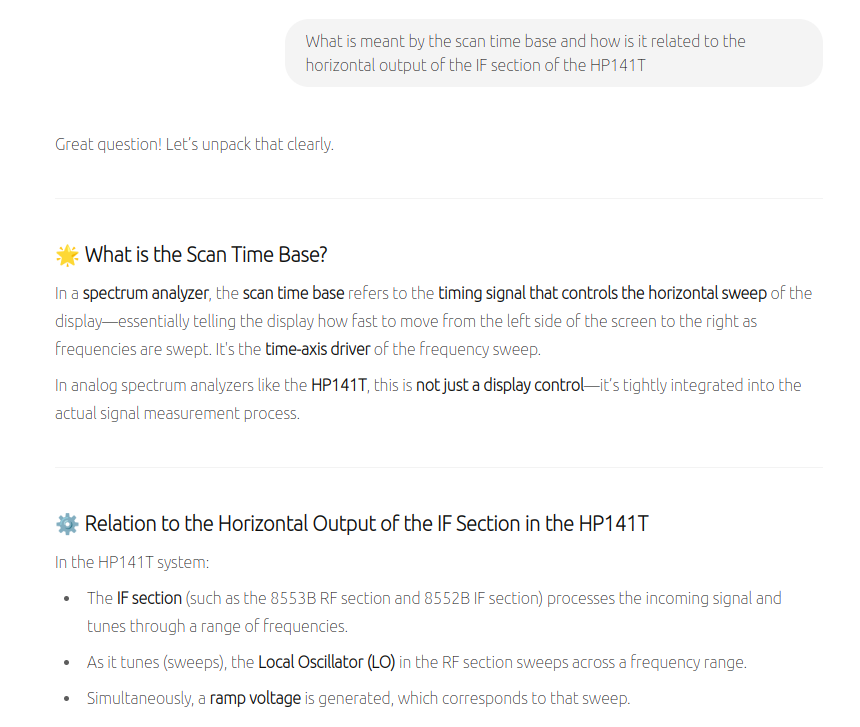
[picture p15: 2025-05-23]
Report/Figures/Appendices/clarification.png

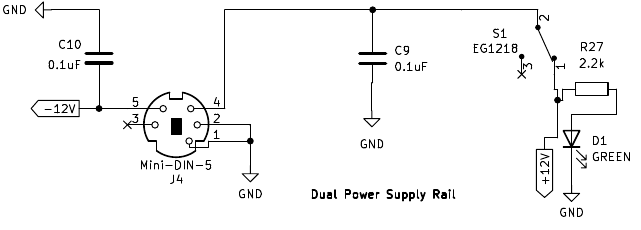
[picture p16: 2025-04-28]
Report/Figures/Methodology/emulator-power-supply.png

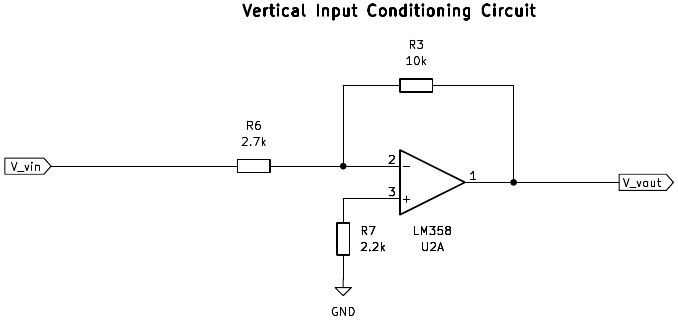
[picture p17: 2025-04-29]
Report/Figures/Methodology/sig-cond-vert-ct-schematic.png

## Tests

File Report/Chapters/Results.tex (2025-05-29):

% ----------------------------------------------------
% Introduction
% ----------------------------------------------------
\documentclass[class=report,11pt,crop=false]{standalone}
\input{../Style/ChapterStyle.tex}
\input{../FrontMatter/Glossary.tex}
\begin{document}

	\chapter{Results and Discussion}
	
	This chapter presents the results obtained from experimental testing of the digitized HP141T system and discusses their significance in the context of the system's performance, fidelity, and ability to meet the specified functional requirements. Each section corresponds to a key subsystem or system-level outcome, integrating quantitative measurements with qualitative assessments to evaluate accuracy, responsiveness, and usability.
	
	\section{HP141T System Test Results}
	
	Due to limited access to the HP141T system with the HP8555A and HP8552B, the Siglent SDG1010 arbitrary waveform generator was used to produce the voltages associated with the vertical, horizontal and pen-lift outputs as described in the datasheet. The test environment, which used the Picoscope 2204 \acrshort{usb} oscilloscope as the measurement device and the Picoscope 7 software as a visualization and analysis tool, is shown in figure \ref{fig:hp141t-test-environment}.
	
	\begin{figure}[h!]
		\centering
		\begin{subfigure}{.33\textwidth}
			\centering
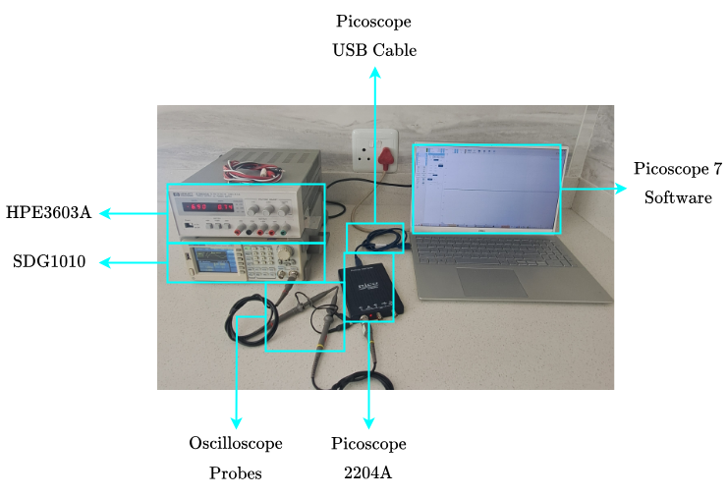
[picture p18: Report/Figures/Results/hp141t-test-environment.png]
			
			\caption{Test environment for waveform generation of HP141T auxiliary outputs.}
			\label{fig:hp141t-test-environment}
		\end{subfigure}%
		\begin{subfigure}{.33\textwidth}
			\centering
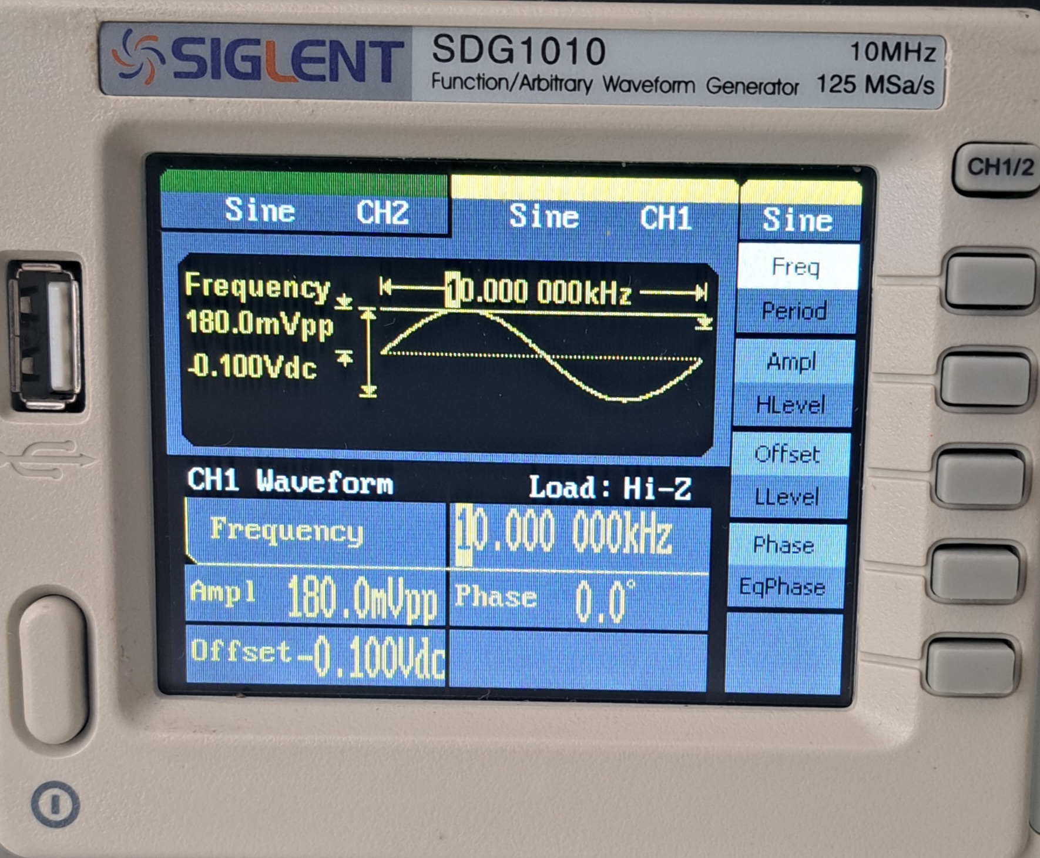
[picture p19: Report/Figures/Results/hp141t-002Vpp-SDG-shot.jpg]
			
			\caption{Example of how the vertical output was setup on the waveform generator.}
			\label{fig:hp141t-002Vpp-SDG-shot}
		\end{subfigure}
		\begin{subfigure}{.33\textwidth}
			\centering
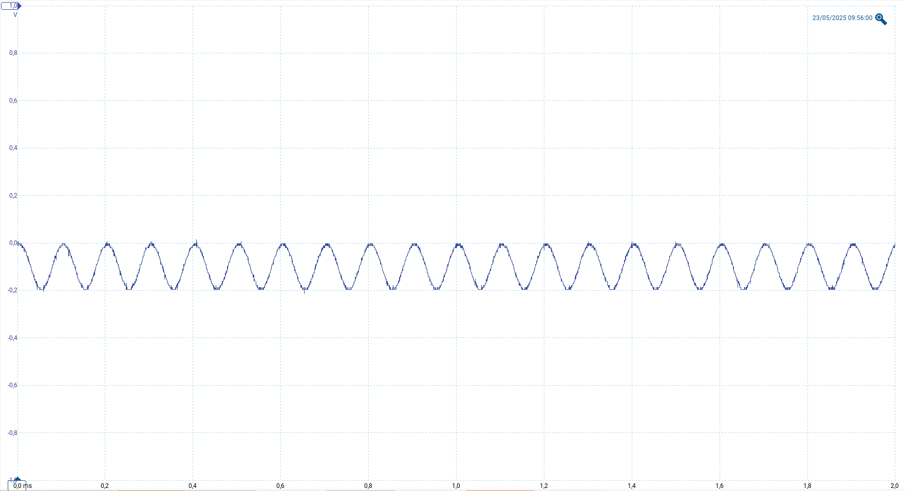
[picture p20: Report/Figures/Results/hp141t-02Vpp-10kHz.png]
			
			\caption{Picoscope display of the waveform generator's $\SI{180}{\milli\volt}_{pp}$ ($\SI{10}{\kilo\hertz}$) output setup shown alongside.}
			\label{fig:hp141t-002Vpp}
		\end{subfigure}
		\caption{Test environment for the approximating outputs of the HP8552B plug-in section.}
		\label{fig:hp141t-test-hardware}
	\end{figure} 

	A sinusoidal waveform was used to approximate the vertical output of the HP141T using the SDG1010 waveform generator as seen in the figures in \ref{fig:hp141t-test-hardware}. A sinusoidal waveform was found to be suitable for testing because it enabled fine adjustments of the amplitude and frequency with accurate measurements. 
	
	The characteristics of the approximate vertical output were analyzed in the Picoscope 7 software, as depicted in figure \ref{fig:hp141t-002Vpp} which shows a display of time domain characteristics of the wave generator output. Together, the results from the Picoscope software in figure \ref{fig:hp141t-test-hardware} showed that to generate the vertical output signal with a peak voltage at $\SI{0}{\volt}$, a minimum voltage of $-\SI{200}{\milli\volt}$, and frequency of $\SI{10}{\kilo\hertz}$, the amplitude of the wave from the SDG1010 should be set to $\SI{180}{\milli\volt}$ with an offset of $-\SI{100}{\milli\volt}$. This implied that the peak-to-peak voltage of the waveform from the SDG1010 deviated from the true value by $10\%$.
	
	Further investigation into the deviation of the output peak-to-peak voltage from the value set on the waveform generator was conducted by performing measurements with different voltage between $\SI{0}{\milli\volt}$ and $-\SI{0.8}{\volt}$. The results from the investigation are illustrated in figure \ref{fig:hp141t-vert-test-results} and summarized in table 4.1. 
	
	\begin{figure}[h!]
		\centering
		\begin{subfigure}{.32\textwidth}
			\centering
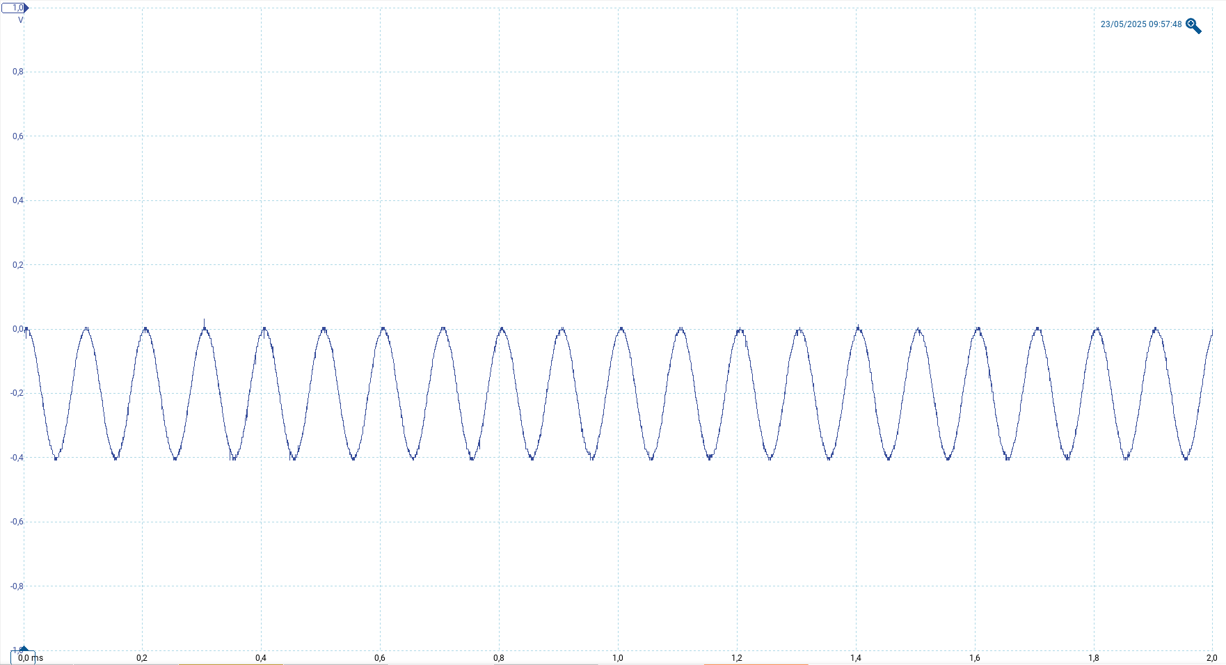
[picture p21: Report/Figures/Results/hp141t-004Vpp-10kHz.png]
			
			\caption{A peak-to-peak output voltage of $\SI{400}{\milli\volt}$ for an input waveform set to $\SI{180}{\milli\volt}$ at $\SI{10}{\kilo\hertz}$.}
			\label{fig:hp141t-04Vpp-10kHz}
		\end{subfigure}%
		\begin{subfigure}{.32\textwidth}
			\centering
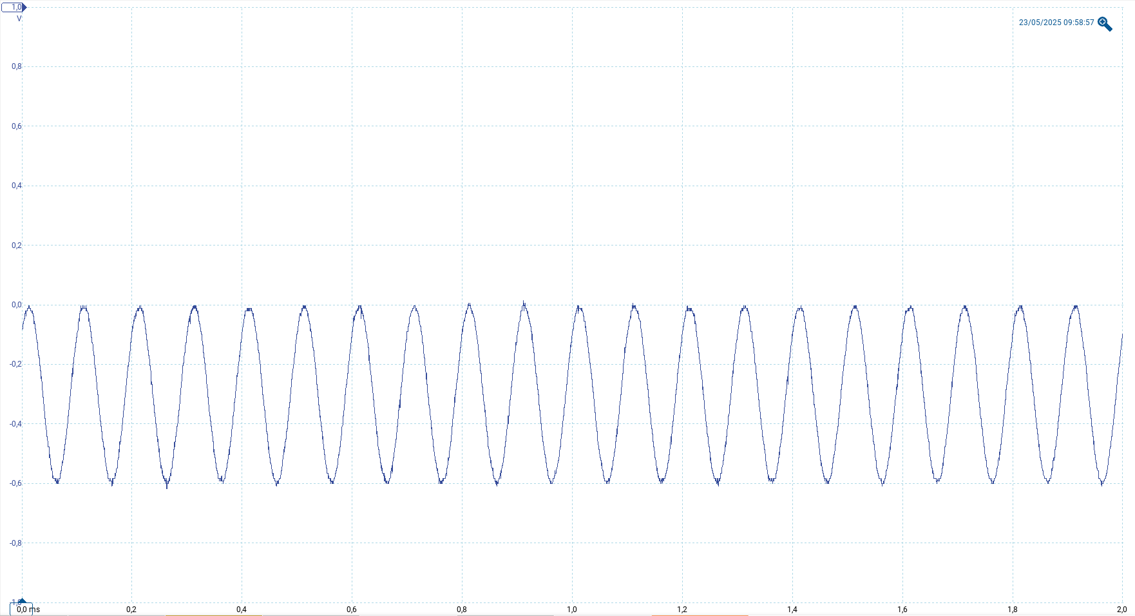
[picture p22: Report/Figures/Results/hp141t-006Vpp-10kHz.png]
			
			\caption{A peak-to-peak output voltage of $\SI{600}{\milli\volt}$ for an input waveform set to $\SI{260}{\milli\volt}$ at $\SI{10}{\kilo\hertz}$.}
			\label{fig:hp141t-006Vpp-result}
		\end{subfigure}
		\begin{subfigure}{.32\textwidth}
			\centering
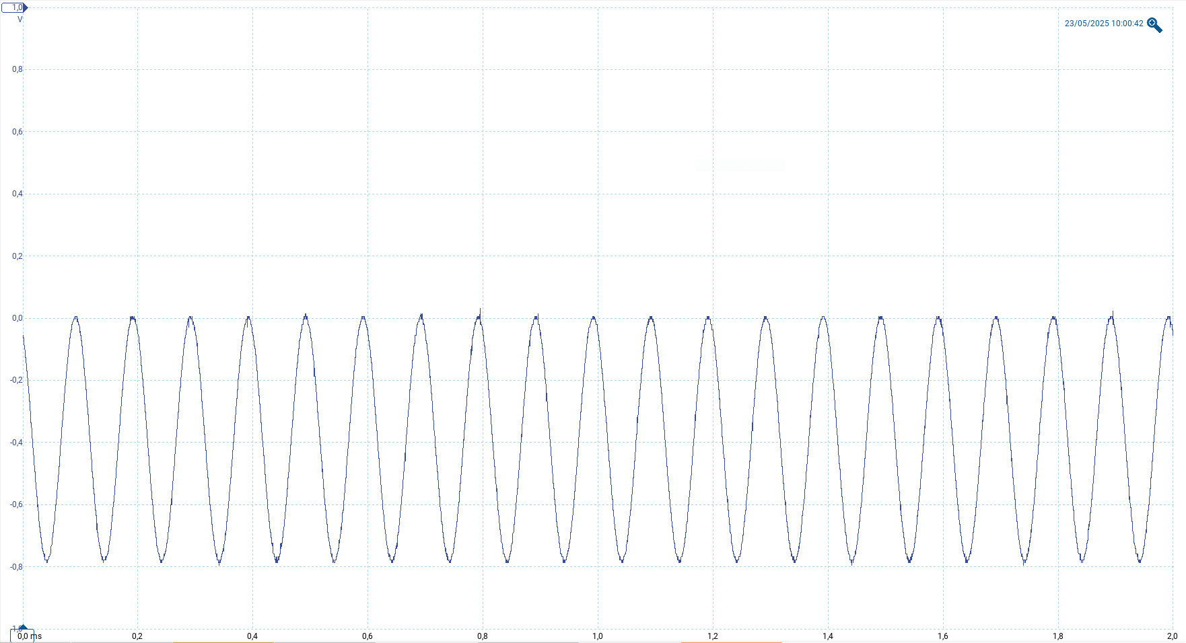
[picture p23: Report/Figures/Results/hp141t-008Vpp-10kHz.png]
			
			\caption{A peak-to-peak output voltage of $\SI{800}{\milli\volt}$ for an input waveform set to $\SI{320}{\milli\volt}$ at $\SI{10}{\kilo\hertz}$.}
			\label{fig:hp141t-008Vpp-result}
		\end{subfigure}
		\caption{Results from the investigation of the relationship between the vertical output's peak-to-peak voltage settings on the SDG1010 and the measured peak-to-peak voltage in Picoscope 7. The frequency and phase were maintained at constant values of $\SI{10}{\kilo\hertz}$ and $\SI{0}{\degree}$, respectively.}
		\label{fig:hp141t-vert-test-results}
	\end{figure} 
	
	In each case, an adjustment was required setup the SDG1010 such that the output has negative values between $\SI{0}{\volt}$ and $-\SI{0.800}{\volt}$. Results also showed that smaller voltage ranges between $\SI{0}{\milli\volt}$ and $-\SI{0.4}{\volt}$ were more susceptible to noise. This was observed from the increase in the smoothness of the displayed output in the Picoscope \acrshort{ui}.
	
	\begin{table}[ht!]
		\centering
		\label{tab:hp141t-vert-test-results}
		\begin{tabular}{|m{5em}|m{8em}|m{8em}|m{8em}|m{8em}|}
			\hline
			\textbf{Assessment ID} & \textbf{Measured Peak-to-Peak Value} (V)	& \textbf{Set Value} (V) & \textbf{Set Offset} (V) & \textbf{Measurement Accuracy} ($\%$)\\
			\hline
			1 & $0.202$ & $0.197$ & $-0.100$ & $2.5$\\
			\hline
			2 & $0.398$ & $0.390$ & $-0.200$ & $2.1$\\
			\hline
			3 & $0.600$ & $0.576$ & $-0.300$ & $4.2$\\
			\hline
			4 & $0.800$ & $0.765$ & $-0.400$ & $4.6$\\
			\hline
		\end{tabular}
		\caption{Investigative results of the relationship between the vertical output's peak-to-peak voltage settings on the SDG1010 and the measured peak-to-peak voltage in Picoscope 7. The frequency and phase were maintained at constant values of $\SI{10}{\kilo\hertz}$ and $\SI{0}{\degree}$, respectively.}
	\end{table}
	The table shows that the percentage accuracy of the test environment for setting up the vertical output decreases as the approximated value approaches a maximum value of $-\SI{0.800}{\volt}$. The measurements were taken starting from a peak-to-peak voltage of $\SI{0.2}{\volt}$. The standard deviation in the measured results was found to be $0.223$ and the standard deviation in the set peak-to-peak values was $0.211$.
	
	Given that some spectrum consist of multiple frequency components, a noisy signal was used to approximate the vertical output more closely as shown in figure \ref{fig:noisy-vertical}. The vertical output from the original HP141T system was expected to fluctuate rapidly with a frequency of up to $\SI{300}{\kilo\hertz}$. To approximate this behaviour using the SDG1010, the standard deviation of the generated Gaussian noise was set to $\SI{136.2}{\milli\volt}$ and the mean was set to $-\SI{360}{\milli\volt}$. 
	\begin{figure}[ht!]
		\centering
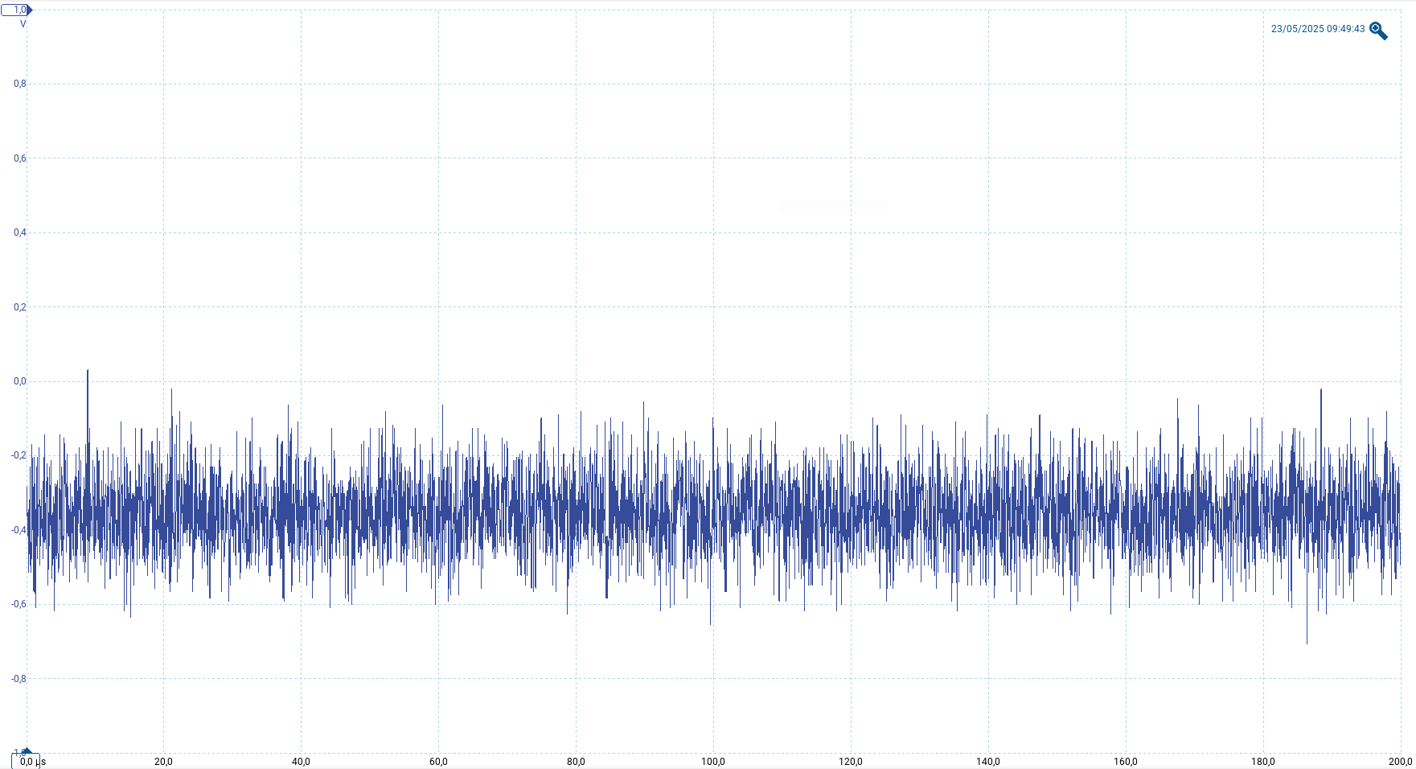
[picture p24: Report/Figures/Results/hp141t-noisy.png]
		
		\caption{Showing approximation of the vertical output with a noisy signal from the wave generator.}
		\label{fig:noisy-vertical}
	\end{figure} 
	
	The horizontal output was also approximated using a waveform generator. However, the sawtooth shape of the signal was approximated using the ramp function on the SDG1010 signal generator. The resultant shape of the output waveform, depicted in figure \ref{fig:hp141t-sawtooth-test}, did not match the desired shape of the HP8552B, as shown in figure \ref{fig:hp8552b-sawtooth}. Therefore, the approximated horizontal output from the SDG1010 could only be used to assess the behaviour of subsequent systems with respect to the amplitude. Although the results of the scan time were considered, the output from the waveform generator does not accurately represent the timing-behaviour of the system when the original HP141T horizontal output is used.
	
	\begin{figure}[h!]
		\centering
		\begin{subfigure}{.48\textwidth}
			\centering
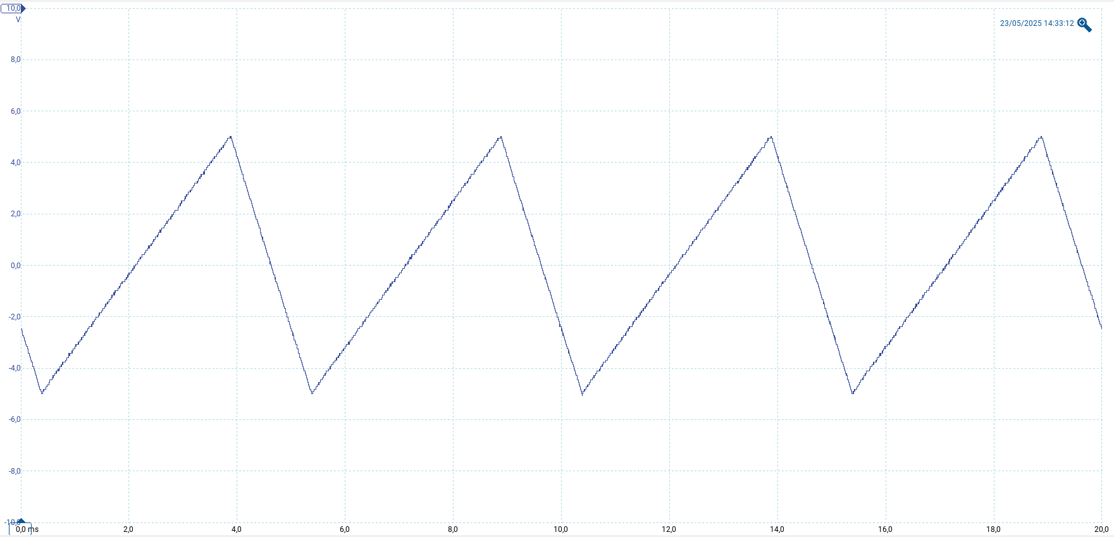
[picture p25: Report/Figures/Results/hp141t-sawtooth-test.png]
			
			\caption{Approximation results of the HP141T's sawtooth scan output using a ramp waveform generated by the SDG1010. The shape of the wave did not approximate the shape of the HP141T output.}
			\label{fig:hp141t-sawtooth-test}
		\end{subfigure}%
		\begin{subfigure}{.48\textwidth}
			\centering
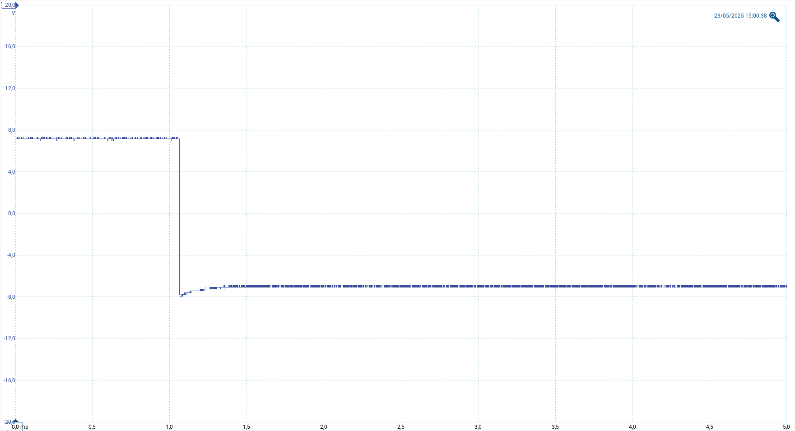
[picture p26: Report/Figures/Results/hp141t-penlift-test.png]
			
			\caption{The pen-lift-output could not be achieved using the SDG1010 as the voltage range was outside of the desired $[\SI{0}{\volt}, \SI{14}{\volt}]$ interval.}
			\label{fig:hp141t-penlift-test}
		\end{subfigure}
		\caption{Test results of the approximated values of the horizontal and pen-lift outputs of the original HP141T system obtained using the Siglent SDG1010.}
		\label{fig:hp141t-horpen-test-results}
	\end{figure} 

	Attempts to approximate the pen-lift output using a square wave generated by the SDG1010 yielded the signal as shown in figure \ref{fig:hp141t-penlift-test}. The maximum value of the output was $\SI{7}{\volt}$ and the minimum value was $\SI{-7}{\volt}$ when the waveform generator was configured to produce a peak-to-peak voltage of $\SI{14}{\volt}$. Given that the SDG1010's maximum allowable offset is $\SI{4.999}{\volt}$, the square wave could not be shifted to fit the desired range of the pen-lift output between $\SI{0}{\volt}$ and $\SI{14}{\volt}$. Therefore, an accurate approximation of the original \acrshort{sa}'s pen-lift output was not achievable using the SDG1010. 
	
	Overall, the unit tests for verifying voltage levels of outputs from the original HP141T system could not be performed directly on the device. However, the results show that the vertical output can be approximated using the SDG1010 with satisfactory accuracy. The results also verify that the Picoscope is a suitable test tool for the system.
	
	\section{HP141T Emulator Subsystem Test Results}
	
	This section presents the results of unit testing the HP141T Emulator \acrshort{pcb}, which is responsible for signal emulation and waveform generation. The tests focus on validating the behavior of the analog outputs (vertical, horizontal, and pen-lift signals) against expected electrical characteristics described in the methodology. Each test verifies waveform amplitude, frequency range, and functional timing to ensure compatibility with downstream processing.
	
	Construction of the HP141T Emulator was completed as shown in figure \ref{fig:emulator-hardware}. The circuit was connected to the HP-E3630A power supply as a required dual rail power supply. The \acrshort{led} associated with the power rail turned on, indicating that electricity was flowing through the circuit to the ground plane.
	
	\begin{figure}[ht!]
		\centering
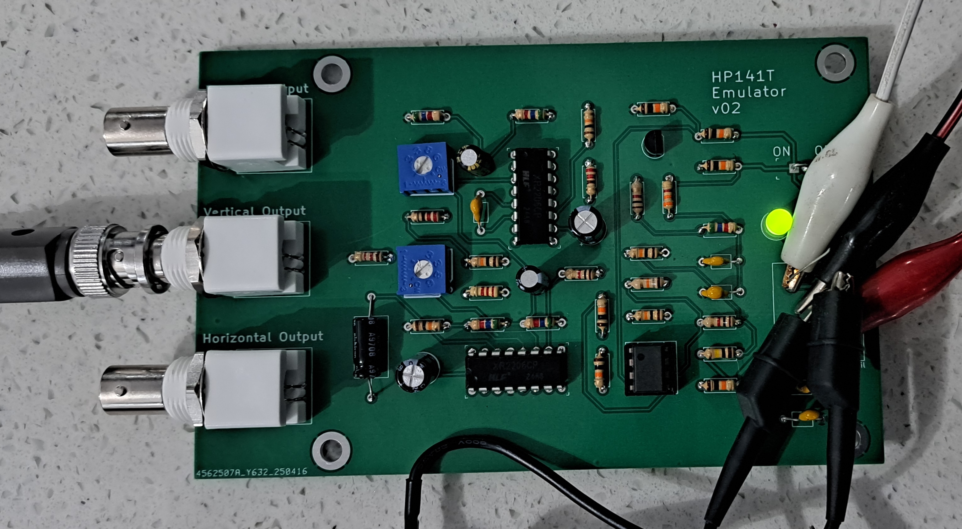
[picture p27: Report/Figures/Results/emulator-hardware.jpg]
		
		\caption{Showing construction of the HP141T Emulator and connection to the HP-E3630 DC power supply. The outputs of the design were collected using a oscilloscope probe connected to the Picoscope and \acrshort{bnc} adapters on the circuit.}
		\label{fig:emulator-hardware}
	\end{figure} 
	
	The graphical results depicted in figure \ref{fig:emulator-output-tests} showed that the HP141T was not operating as expected. This is accounted for by the use of different values for the resistors described in the methodology. The methodology, based on the recommended usage of the XR2206 from the datasheet, uses the E24 resistor series, whereas the available resistors in the laboratory setting belong to the E6 series. In addition, capacitance values were changed according to the availability of the capacitors in the laboratory. 
	
	\begin{figure}[h!]
		\centering
		\begin{subfigure}{.32\textwidth}
			\centering
			
			\caption{Horizontal output from the HP141T Emulator.}
			\label{fig:emulator-horizontal-output}
		\end{subfigure}%
		\begin{subfigure}{.32\textwidth}
			\centering
			
			\caption{Vertical output from the HP141T Emulator.}
			\label{fig:emulator-vertical-output}
		\end{subfigure}
		\begin{subfigure}{.32\textwidth}
			\centering
			
			\caption{Pen-lift output from the HP141T Emulator.}
			\label{fig:emulator-penlift-output}
		\end{subfigure}
		\caption{Results of the HP141T Emulator indicating that the device was not operating as expected.}
		\label{fig:emulator-output-tests}
	\end{figure} 
	
	\begin{table}[ht!]
		\centering
		\begin{tabular}{|c|m{25em}|c|}
			\hline
			\textbf{ID} & \textbf{Description} & \textbf{Outcome} \\
			\hline
			UTB00 & Emulated vertical output ranges between \SI{0}{\volt} and \SI{3.0}{\volt} when a test signal is applied and viewed on the Picoscope. & Fail \\
			\hline
			UTB01 & Spectrum view confirms a \SI{10}{\hertz} component in the vertical output. & Fail \\
			\hline
			UTB02 & Horizontal output shows a sawtooth waveform ranging from \SI{-4.76}{\volt} to \SI{4.75}{\volt}, matching the scan time base configuration. & Fail \\
			\hline
			UTB03 & Pen-lift output toggles between \SI{0}{\volt} (during scan) and \SI{14}{\volt} (during retrace), synchronized with the horizontal sweep. & Fail \\
			\hline
			UTB04 & Power rails meet the expected ranges: +5V $\pm$ 0.1V, -12V $\pm$ 0.2V, and regulated +12V. & Pass \\
			\hline
		\end{tabular}
		\caption{Results of unit tests for the HP141T Emulator \acrshort{pcb}.}
		\label{tab:emulator-unit-tests}
	\end{table}
	Table \ref{tab:emulator-unit-tests} shows the outcomes of the unit tests of the HP141T Emulator. Given that the device did not operate as expected, further iterations are required to improve the performance so that the outputs resemble the HP141T's auxiliary outputs.
	\section{Signal Conditioning Subsystem Results}
	
	This section presents the measured voltage transformations and waveform fidelity at the output of the \acrshort{scs}. It compares the observed behavior against theoretical expectations based on the known input-output mappings, such as the inversion of the vertical output and scaling to the \acrshort{adc}-compatible voltage range.
	
	The \acrshort{scs} was implemented on a \acrshort{pcb} as shown in figure \ref{fig:scs-hardware} where the oscilloscope probe connected to the Picoscope is attached at vertical output of the circuit and the \acrshort{bnc}-to-\acrshort{bnc} adapter is connected to the input adapter and the signal generator. 
	
	\begin{figure}[h!]
		\centering
		\begin{subfigure}{.32\textwidth}
			\centering
			
			\caption{\acrshort{scs} hardware implementation.}
			\label{fig:scs-hardware}
		\end{subfigure}%
		\begin{subfigure}{.32\textwidth}
			\centering
			
			\caption{Vertical output of the \acrshort{scs} \acrshort{pcb} for a $\SI{0.2}{\volt}$ peak-to-peak voltage at $\SI{10}{\kilo\hertz}$.}
			\label{fig:scs-output-02Vpp-10kHz}
		\end{subfigure}
		\begin{subfigure}{.32\textwidth}
			\centering
			
			\caption{Vertical output of the \acrshort{scs} \acrshort{pcb} for a $\SI{0.4}{\volt}$ peak-to-peak voltage at $\SI{10}{\kilo\hertz}$.}
			\label{fig:scs-output-04Vpp-10kHz}
		\end{subfigure}
		\caption{Results from the implementation of the \acrshort{scs} on a \acrshort{pcb}.}
		\label{fig:scs-hardware-implementation}
	\end{figure} 
	
	The results of the \acrshort{scs} were recorded for different peak-to-peak voltages of the SDG1010-generated sinusoidal wave, while maintaining a constant $\SI{10}{\kilo\hertz}$ frequency. When the peak-to-peak voltages on the SDG1010 waveform generator were set according to the results in table \ref{tab:hp141t-vert-test-results}, the displayed output showed that the \acrshort{scs} \acrshort{pcb} was behaving as expected. For example, the output waveform in \ref{fig:scs-output-02Vpp-10kHz} shows that when an input with a peak-to-peak voltage of $-\SI{0.2}{\volt}$ was injected into the subsystem, the output of the \acrshort{scs} was $\SI{0.7}{\volt}$, showing that the subsystem adequately inverted and scaled the output to a value within the desired range between $\SI{0}{\volt}$ and $\SI{3.3}{\volt}$. Additionally, the shape of the \acrshort{scs}'s output waveform resembled the shape of simulated outputs where the base of the waveform is clipped. This is illustrated in figure \ref{fig:scs-output-02Vpp-10kHz} and \ref{fig:scs-output-04Vpp-10kHz}.
	
	Clipping effects were found to be more evident for larger peak-to-peak voltages. For example, the maximum voltage of the vertical input was set to $-\SI{0.8}{\volt}$, the resultant shape of the output was more significantly clipped. This can be seen in figure \ref{fig:scs-output-08Vpp-10kHz}. An experiment was conducted to verify simulation results which showed that waveform clipping was reduced as the frequency increased. In the experiment, the voltage was maintained at a constant peak-to-peak voltage of $\SI{0.8}{\volt}$ ($\SI{0}{\volt}$ to $-\SI{0.8}{\volt}$) while the frequency was varied up to $\SI{300}{\kilo\hertz}$.  
	
	\begin{figure}[ht!]
		\centering
		\begin{subfigure}{.32\textwidth}
			\centering
			
			\caption{Results showing significant clipping for larger peak-to-peak voltages.}
			\label{fig:scs-output-08Vpp-10kHz}
		\end{subfigure}%
		\begin{subfigure}{.32\textwidth}
			\centering
			
			\caption{Waveform clipping analysis for a frequency of $\SI{100}{\kilo\hertz}$.}
			\label{fig:scs-output-08Vpp-100kHz}
		\end{subfigure}
		\begin{subfigure}{.32\textwidth}s
			\centering
			
			\caption{Waveform clipping analysis for a frequency of $\SI{300}{\kilo\hertz}$.}
			\label{fig:scs-output-08Vpp-300kHz}
		\end{subfigure}
		\caption{Results showing the effect of increasing the frequency on the amount of voltage clipping at the output of the \acrshort{scs}.}
		\label{fig:scs-frequency}
	\end{figure} 
	The results show that although clipping is reduced as the frequency is increased, the shape of the output began to collapse to a triangular wave. Additionally, the results in figure \ref{fig:scs-frequency} showed that the peak-to-peak voltage of the \acrshort{scs} output was scaled down and shifted up as the frequency increased. 
	
	Additional results were taken to analyze the response of the subsystem to noisy inputs by supplying a Gaussian noise from the SDG1010. The input Gaussian noise was given a standard deviation of $\SI{136.2}{\milli\volt}$ and a mean voltage of $-\SI{360}{\milli\volt}$ as shown in figure \ref{fig:noisy-vertical}. The \acrshort{scs} showed adequate behaviour because the output voltage was within the range of $\SI{0}{\volt}$ to $\SI{3.3}{\volt}$, as seen in figure \ref{fig:scs-noisy-signal-test}.
	
	\begin{figure}[ht!]
		\centering
		
		\caption{Results showing a satisfactory response of the \acrshort{scs} to a noisy vertical input signal.}
		\label{fig:scs-noisy-signal-test}
	\end{figure} 
		
	\begin{table}[ht!]
		\centering
		\begin{tabular}{|c|m{25em}|c|}
			\hline
			\textbf{ID} & \textbf{Description} & \textbf{Outcome} \\
			\hline
			UTC00 & Power the \acrshort{scs} \acrshort{pcb} with a \SI{9}{\volt} supply. Verify that the green LED indicator turns on, confirming power is applied correctly. & Pass \\
			\hline
			UTC01 & Apply a known input to the vertical path. Verify inversion and linear scaling from $-\SI{0.8}{\volt}$ to $\SI{0}{\volt}$ mapped to $\SI{0}{\volt}$ to $\SI{3.3}{\volt}$. & Pass \\
			\hline
			UTC02 & Apply a sawtooth waveform to the horizontal path and confirm that it is linearly scaled from $\pm\SI{5}{\volt}$ to $\SI{0}{\volt}$–$\SI{3.3}{\volt}$ at the output. & Pass \\
			\hline
			UTC03 & Induce a pen-lift event and verify that the signal toggles between \SI{0}{\volt} (scan active) and \SI{3.3}{\volt} (blanking active). & Pass \\
			\hline
			UTC04 & Use high-resolution mode to check for signal ripple. Confirm that peak-to-peak noise remains below \SI{20}{\milli\volt} with no distortion. & Pass \\
			\hline
			UTC05 & Apply out-of-range voltages ($\pm\SI{10}{\volt}$) to inputs. Ensure the output remains clamped and does not exceed safe ADC levels. & Pass \\
			\hline
		\end{tabular}
		\caption{Unit test results for the \acrshort{scs}.}
		\label{tab:scs-unit-tests}
	\end{table}
	
	Outcomes of the unit tests for the subsystem are included in table \ref{tab:scs-unit-test-results}, showing satisfactory behaviour which closely approximates simulated results.
	
	\section{Data Acquisition Subsystem Results}
	
	This section evaluates how reliably the \acrshort{das} converts conditioned analog signals into digital format and stores them in the required \texttt{.csv} structure for downstream processing. Due to the limited availability of the high performance STM32H723ZG microcontroller, the Picoscope 2204A was used as the sampling device in the \acrshort{das}. This was expected to affect the real-time performance of the system. 
	
	To acquire data using the Picoscope, the vertical output of the \acrshort{scs} was connected to channel A while the Picoscope 7 software was opened. While the program running, the \texttt{Save} button was pressed and the file type was set to \texttt{.csv}. The \texttt{.csv} file was saved on the local machine with columns as shown in figure \ref{fig:das-csv}. 
	
	\begin{figure}[ht!]
		\centering
		
		\caption{Showing how data was stored using the Picoscope to generate \texttt{.csv} files for processing in the \acrshort{dsp}.}
		\label{fig:das-csv}
	\end{figure} 
	
	Each \texttt{.csv} file contained 6257 data points, which is sufficient to satisfy the requirement for 801 samples per second. The column with the time-stamps indicated that data points were sampled at intervals of $\SI{0.0003}{\second}$, implying that the sampling frequency of the \acrshort{adc}s on the Picoscope was $\SI{3.3}{\kilo\hertz}$. 
	 
	\section{Digital Processing and Graphical User Interface Results}
	
	This section evaluates the performance of the \acrshort{guis} in terms of visual accuracy, responsiveness, and user experience. Test results include display scaling verification, update latency, and the reliability of interactive controls for switching between display modes. Screenshots and user feedback may be used to support the discussion. Here, the combined behavior of all subsystems is evaluated to assess how well the full digitized HP141T meets its intended purpose. System level outputs are compared with those of the original HP141T to discuss emulation fidelity. Particular focus is placed on real-time performance, mode switching, and overall usability. 
	
	The \acrshort{dps} and \acrshort{guis} were executed based on the \acrshort{rpi} 4B \acrshort{sbc} as shown in figure \ref{fig:rpi-4b-guis}. The \acrshort{rpi} was mounted to the back of the 7 inch touchscreen display and the video cable was connected to both devices. 
	
	\begin{figure}[ht!]
		\centering
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

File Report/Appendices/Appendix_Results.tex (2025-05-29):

% ----------------------------------------------------
% Introduction
% ----------------------------------------------------
\documentclass[class=report,11pt,crop=false]{standalone}
\input{../Style/ChapterStyle.tex}
\input{../FrontMatter/Glossary.tex}
\begin{document}
	% ----------------------------------------------------
	\chapter{Appendix}

	\section{AI Usage History}
	
	\subsection{Prompts for Debugging}
	
	\ifstandalone
	\bibliography{../Bibliography/References.bib}
	\printnoidxglossary[type=\acronymtype,nonumberlist]
	\fi
\end{document}
% ----------------------------------------------------

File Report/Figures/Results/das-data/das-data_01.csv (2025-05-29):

Time | Channel A
(ms) | (V)
0,00000000 | 1,20776999
0,00032000 | 1,16412854
0,00064000 | 1,12063968
0,00096000 | 1,07699823
0,00128000 | 1,07699823
0,00160000 | 1,03335667
0,00192000 | 0,98986781
0,00224000 | 0,98986781
0,00256000 | 0,94622642
0,00288000 | 0,94622642
0,00320000 | 0,90273750
0,00352000 | 0,85909605
0,00384000 | 0,85909605
0,00416000 | 0,81560719
0,00448000 | 0,81560719
0,00480000 | 0,77196568
0,00512000 | 0,72847676
0,00544000 | 0,72847676
0,00576000 | 0,72847676
0,00608000 | 0,68483531
0,00640000 | 0,64134651
0,00672000 | 0,59770501
0,00704000 | 0,59770501
0,00736000 | 0,55421615
0,00768000 | 0,55421615
0,00800000 | 0,51057464
0,00832000 | 0,51057464
0,00864000 | 0,46708581
0,00896000 | 0,42344433
0,00928000 | 0,42344433
0,00960000 | 0,37995544
0,00992000 | 0,37995544
0,01024000 | 0,37995544
0,01056000 | 0,33646658
0,01088000 | 0,33646658
0,01120000 | 0,29282510
0,01152000 | 0,29282510
0,01184000 | 0,24933621
0,01216000 | 0,24933621
0,01248000 | 0,24933621
0,01280000 | 0,20569475
0,01312000 | 0,20569475
0,01344000 | 0,20569475
0,01376000 | 0,16220587
0,01408000 | 0,16220587
0,01440000 | 0,16220587
0,01472000 | 0,11856440
0,01504000 | 0,11856440
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

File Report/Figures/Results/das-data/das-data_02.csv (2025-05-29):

Time | Channel A
(ms) | (V)
0,00000000 | 1,55629146
0,00032000 | 1,59978032
0,00064000 | 1,59978032
0,00096000 | 1,64342177
0,00128000 | 1,68691051
0,00160000 | 1,73055196
0,00192000 | 1,73055196
0,00224000 | 1,77419353
0,00256000 | 1,77419353
0,00288000 | 1,81768239
0,00320000 | 1,86132383
0,00352000 | 1,90481281
0,00384000 | 1,90481281
0,00416000 | 1,94845426
0,00448000 | 1,94845426
0,00480000 | 1,99194312
0,00512000 | 2,03558469
0,00544000 | 2,07907343
0,00576000 | 2,12271500
0,00608000 | 2,12271500
0,00640000 | 2,16620398
0,00672000 | 2,16620398
0,00704000 | 2,20984530
0,00736000 | 2,25333405
0,00768000 | 2,25333405
0,00800000 | 2,29697561
0,00832000 | 2,29697561
0,00864000 | 2,29697561
0,00896000 | 2,38410592
0,00928000 | 2,38410592
0,00960000 | 2,38410592
0,00992000 | 2,47123623
0,01024000 | 2,47123623
0,01056000 | 2,47123623
0,01088000 | 2,47123623
0,01120000 | 2,51487780
0,01152000 | 2,55836678
0,01184000 | 2,55836678
0,01216000 | 2,60200787
0,01248000 | 2,60200787
0,01280000 | 2,64549708
0,01312000 | 2,64549708
0,01344000 | 2,64549708
0,01376000 | 2,68913841
0,01408000 | 2,68913841
0,01440000 | 2,73262739
0,01472000 | 2,73262739
0,01504000 | 2,73262739
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

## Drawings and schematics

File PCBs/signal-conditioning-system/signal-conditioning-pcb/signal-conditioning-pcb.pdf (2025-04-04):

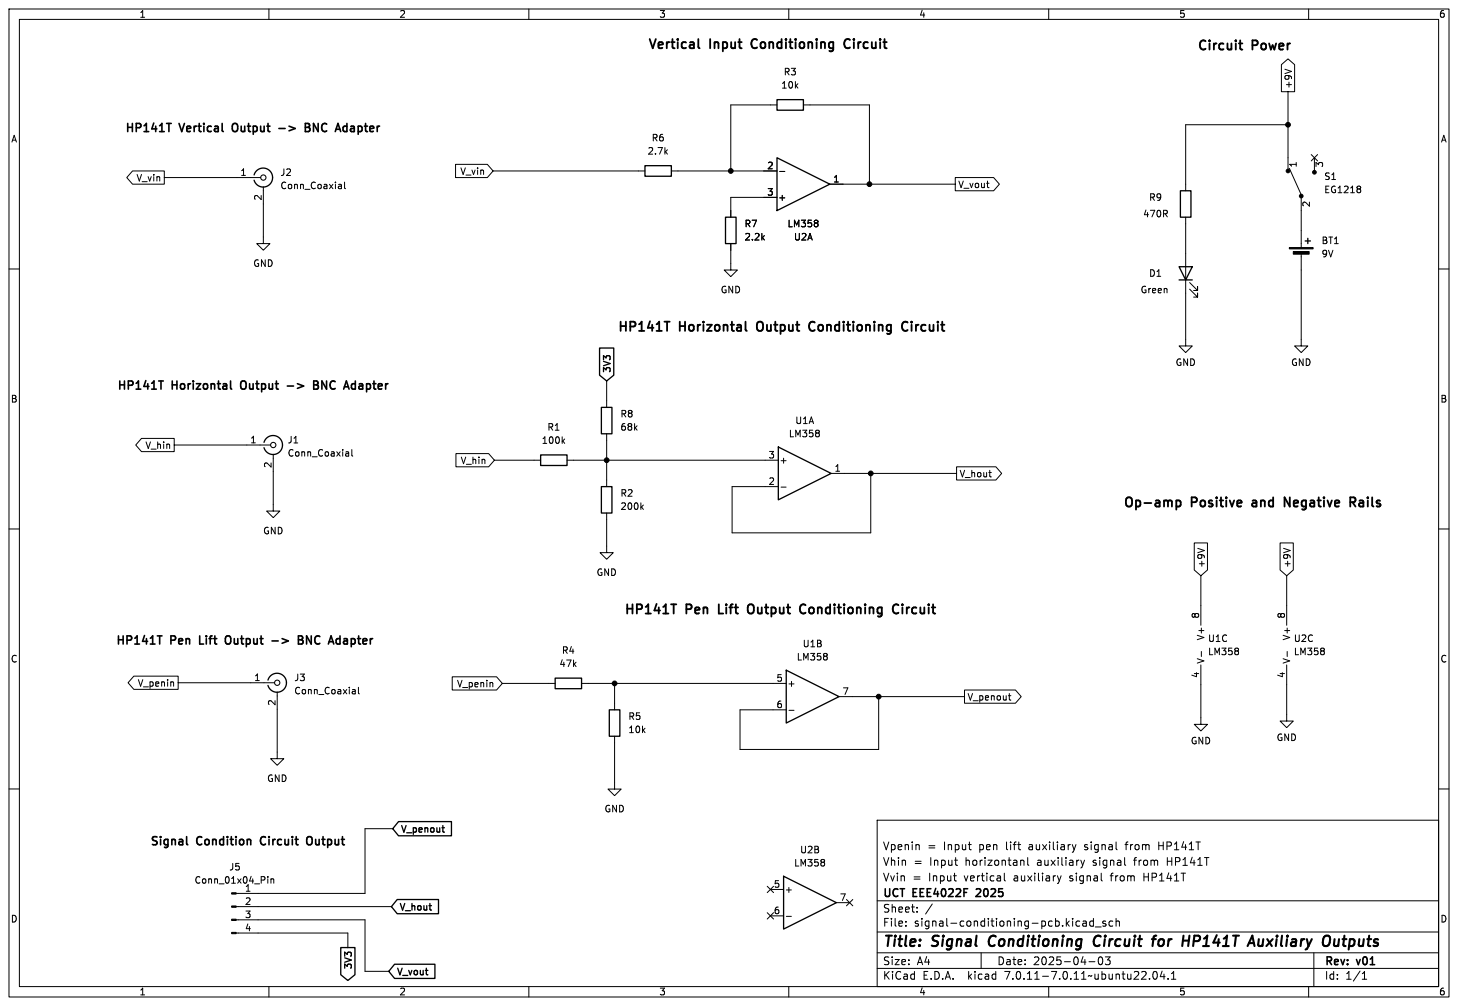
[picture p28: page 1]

HP141T Pen Lift Output Conditioning Circuit

Signal Condition Circuit Output

Id: 1/1 Title: Signal Conditioning Circuit for HP141T Auxiliary Outputs

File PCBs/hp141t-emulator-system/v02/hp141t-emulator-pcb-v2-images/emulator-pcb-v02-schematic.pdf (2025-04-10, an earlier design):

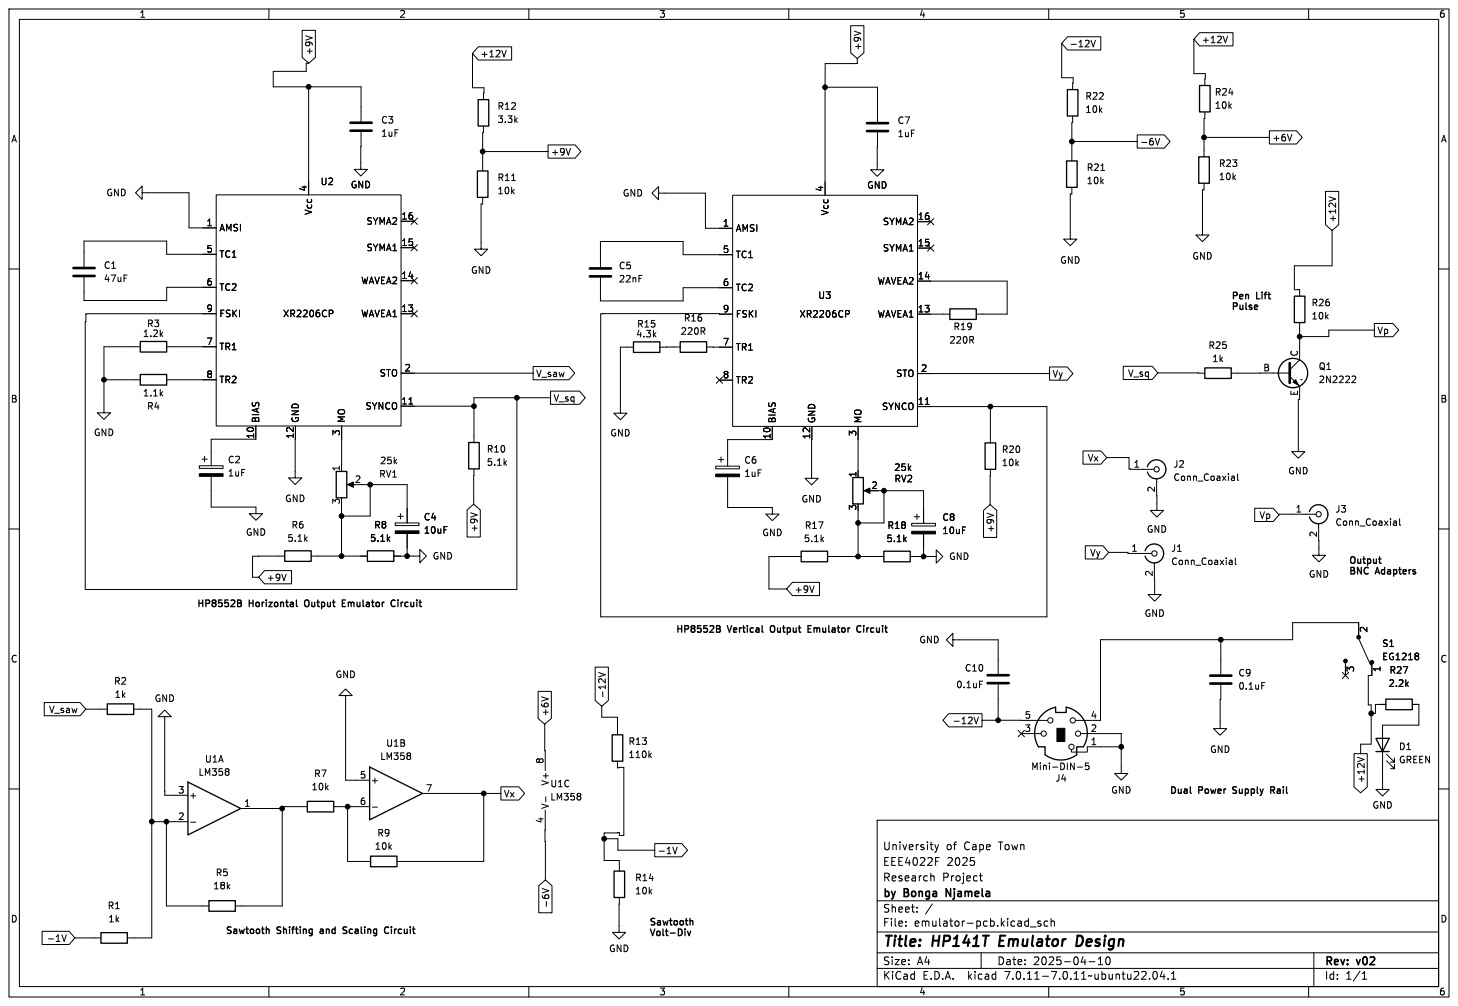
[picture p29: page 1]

3 Vcc 4 TC1 5 TC2 6 TR1 7 TR2 8 FSKI 9 U3 XR2206CP GND GND

Id: 1/1 Title: HP141T Emulator Design

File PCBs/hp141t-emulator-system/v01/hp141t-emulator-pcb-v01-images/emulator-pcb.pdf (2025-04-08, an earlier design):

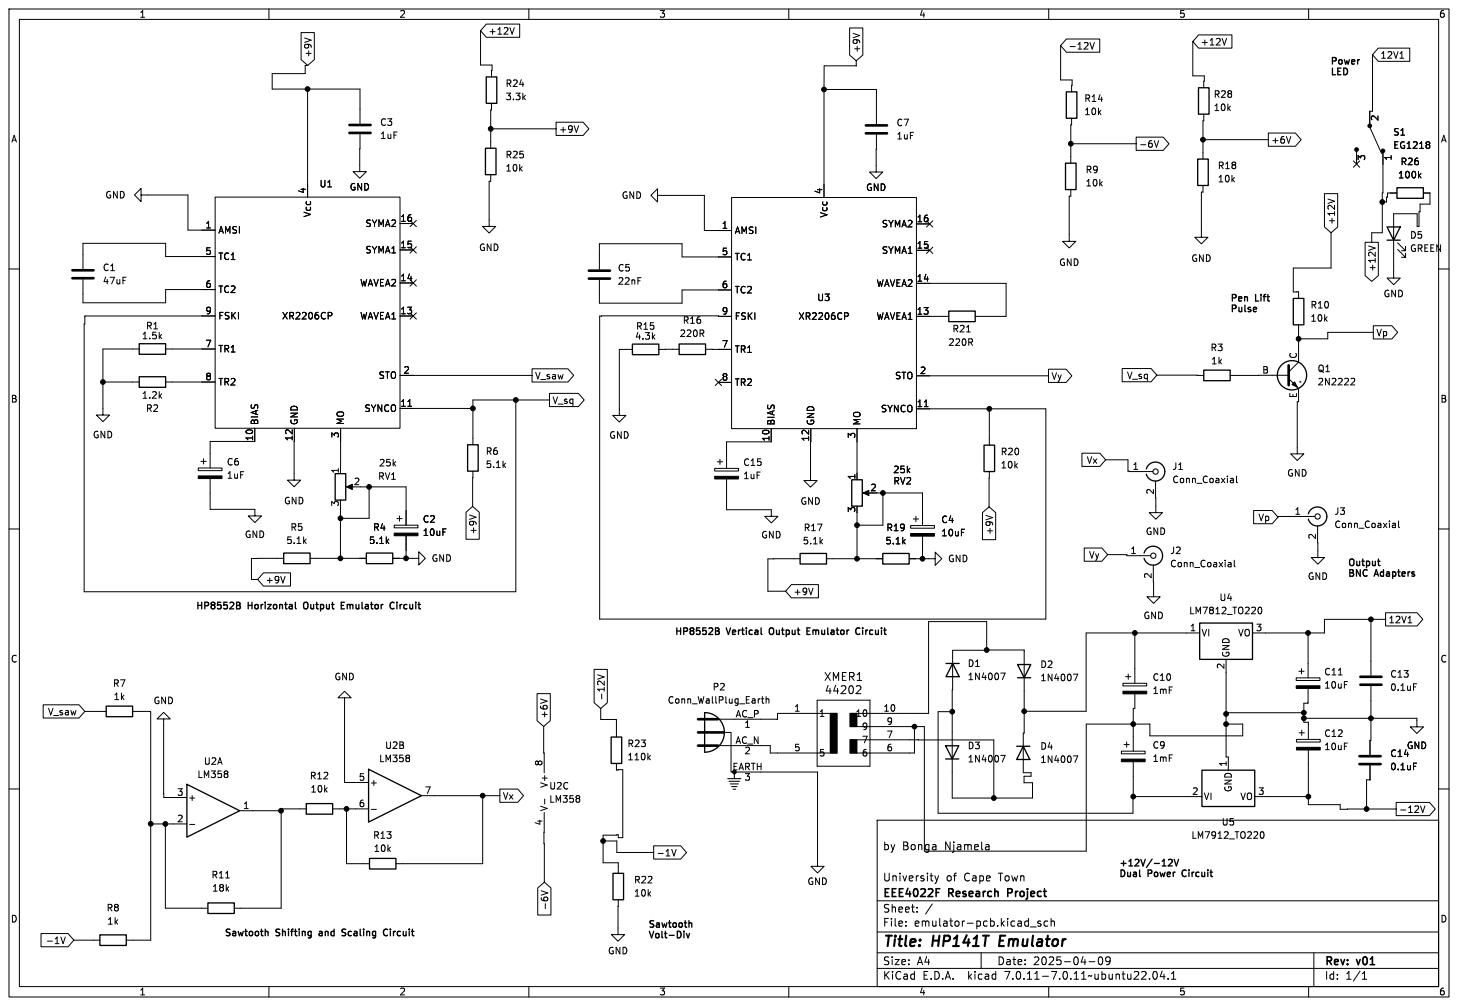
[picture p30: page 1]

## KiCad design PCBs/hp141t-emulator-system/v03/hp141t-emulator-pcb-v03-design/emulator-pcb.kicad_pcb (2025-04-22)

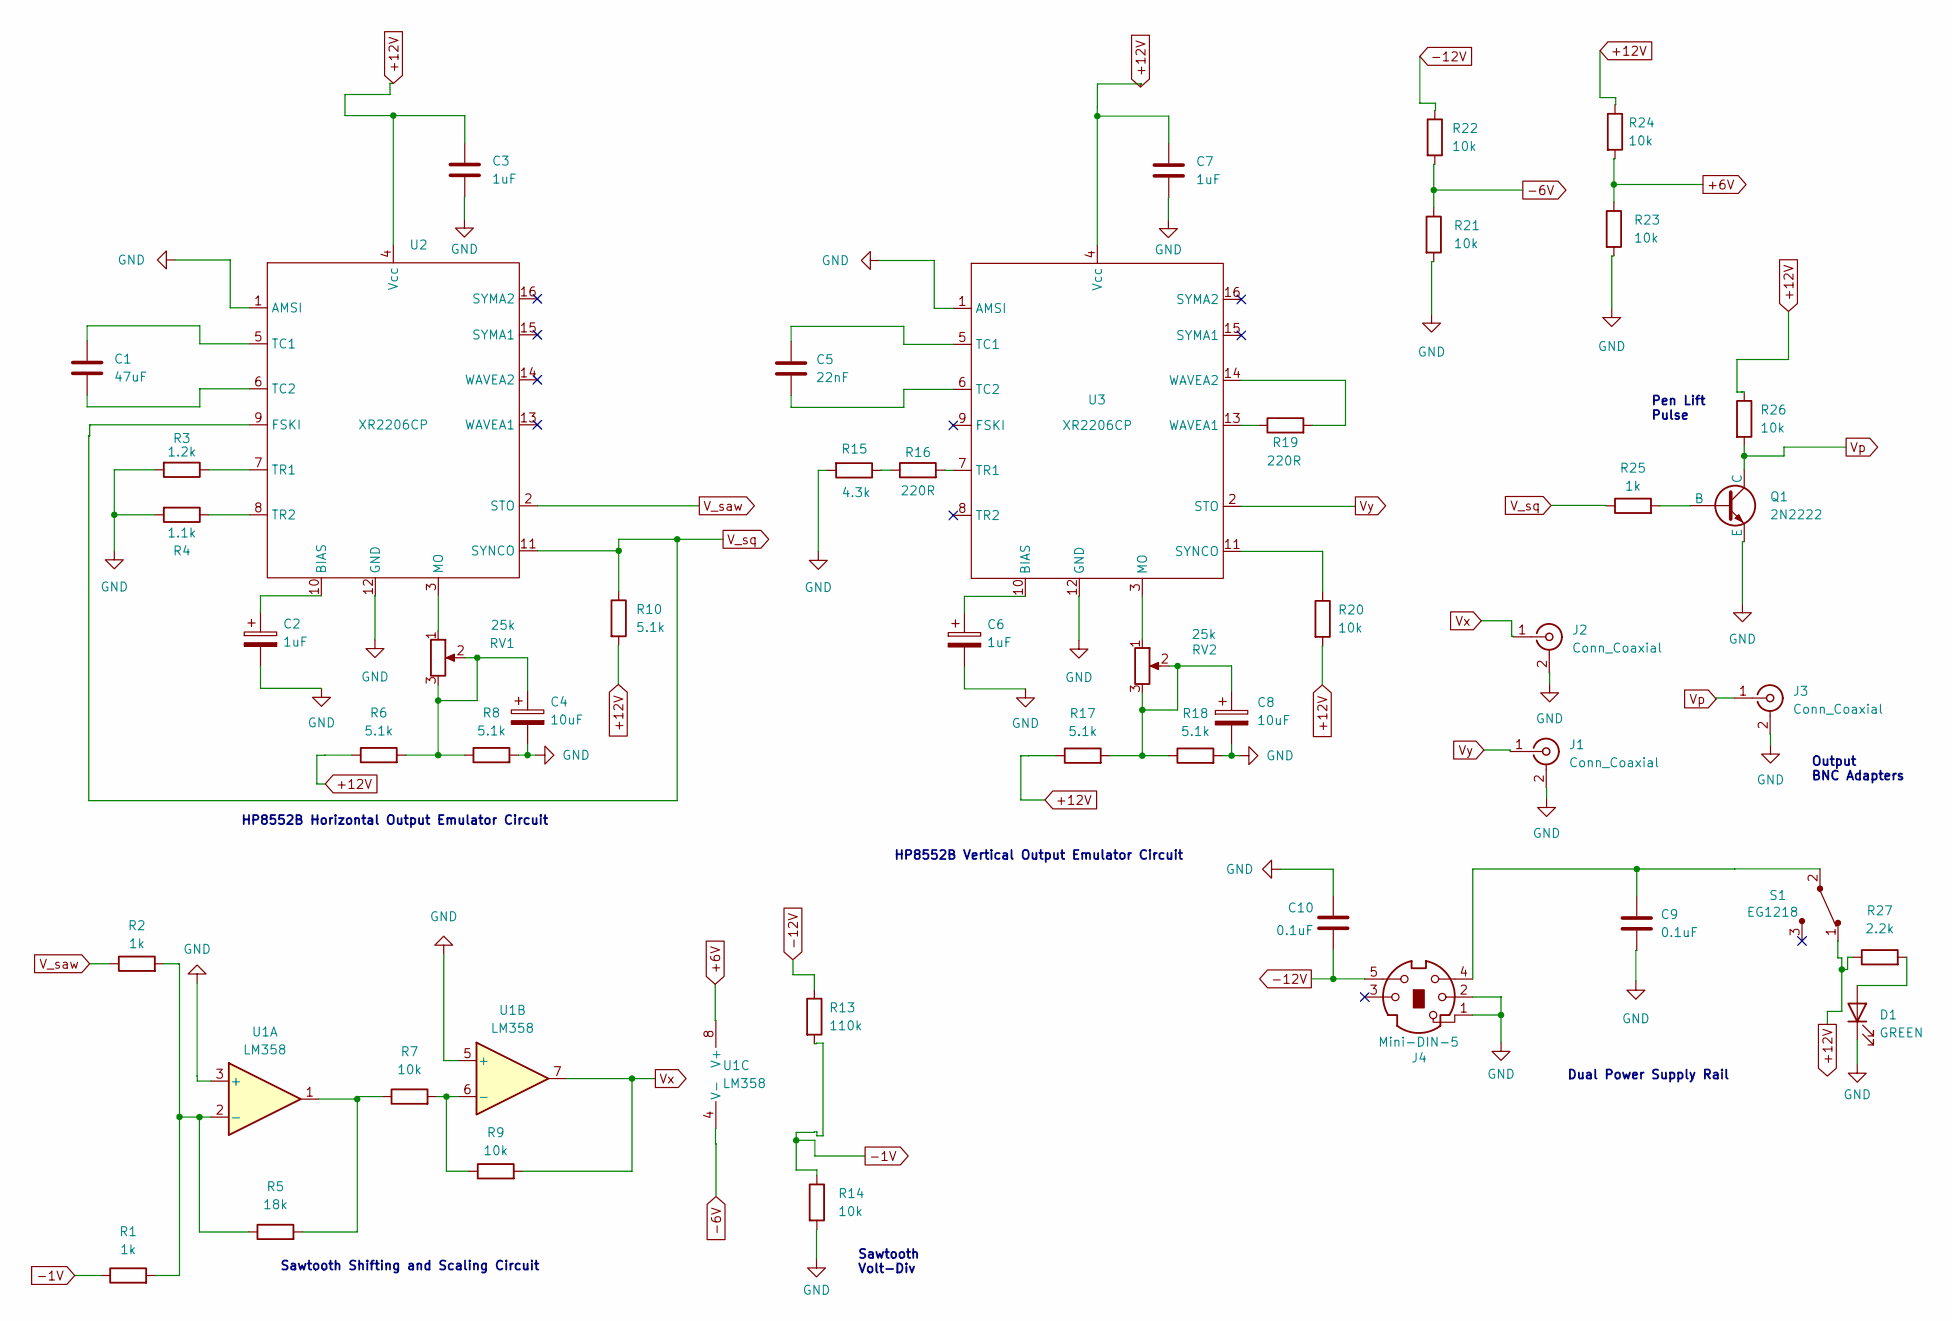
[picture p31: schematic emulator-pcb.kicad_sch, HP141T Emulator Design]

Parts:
C1: 47uF; C_Axial_L12.0mm_D6.5mm_P20.00mm_Horizontal
C2, C6: 1uF; CP_Radial_D6.3mm_P2.50mm
C3, C7: 1uF; C_Axial_L3.8mm_D2.6mm_P7.50mm_Horizontal
C4, C8: 10uF; CP_Radial_D4.0mm_P1.50mm
C5: 22nF; C_Axial_L3.8mm_D2.6mm_P7.50mm_Horizontal
C9, C10: 0.1uF; C_Axial_L3.8mm_D2.6mm_P7.50mm_Horizontal
D1: GREEN; LED_D5.0mm
J1, J2, J3: Conn_Coaxial; BNC_Amphenol_B6252HB-NPP3G-50_Horizontal
J4: Mini-DIN-5; PinSocket_DIN41524_1x05_P2.54mm_Vertical
Q1: 2N2222; TO-92_Inline
R1, R2, R25: 1k; R_Axial_DIN0207_L6.3mm_D2.5mm_P7.62mm_Horizontal
R3: 1.2k; R_Axial_DIN0207_L6.3mm_D2.5mm_P7.62mm_Horizontal
R4: 1.1k; R_Axial_DIN0207_L6.3mm_D2.5mm_P7.62mm_Horizontal
R5: 18k; R_Axial_DIN0207_L6.3mm_D2.5mm_P7.62mm_Horizontal
R6, R8, R10, R17, R18: 5.1k; R_Axial_DIN0207_L6.3mm_D2.5mm_P7.62mm_Horizontal
R7, R9, R14, R20, R21, R22, R23, R24, R26: 10k; R_Axial_DIN0207_L6.3mm_D2.5mm_P7.62mm_Horizontal
R13: 110k; R_Axial_DIN0207_L6.3mm_D2.5mm_P7.62mm_Horizontal
R15: 4.3k; R_Axial_DIN0207_L6.3mm_D2.5mm_P7.62mm_Horizontal
R16, R19: 220R; R_Axial_DIN0207_L6.3mm_D2.5mm_P7.62mm_Horizontal
R27: 2.2k; R_Axial_DIN0207_L6.3mm_D2.5mm_P7.62mm_Horizontal
RV1, RV2: 25k; BOURNS-3362P_pot
S1: EG1218; Switch_Slide_11.6x4mm_EG1218; MPN EG1218; Digi-Key_PN EG1903-ND
U1: LM358; DIP-8_W7.62mm_Socket
U2, U3: XR2206CP; Socket_DIP-16_7.62mm_Conn

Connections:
+6V: R23.1, R24.2, U1.8 (V+)
+12V: C3.1, C7.1, R6.1, R10.2, R17.1, R20.2, R24.1, R26.1, R27.1, S1.1, U2.4 (Vcc), U3.4 (Vcc)
-1V: R1.1, R13.2, R14.1
-6V: R21.1, R22.2, U1.4 (V-)
-12V: C10.2, J4.5, R13.1, R22.1
GND: C2.2, C3.2, C4.2, C6.2, C7.2, C8.2, C9.2, C10.1, D1.1 (K), J1.2 (Ext), J2.2 (Ext), J3.2 (Ext), J4.1, J4.2, Q1.3 (E), R3.2, R4.2, R8.2, R14.2, R15.2, R18.2, R21.2, R23.2, U1.3 (+), U1.5 (+), U2.1 (AMSI), U2.12 (GND), U3.1 (AMSI), U3.12 (GND); also elsewhere on the board
unnamed: C4.1, R6.2, R8.1, RV1.2, RV1.3
unnamed: C8.1, R17.2, R18.1, RV2.2, RV2.3
unnamed: C9.1, J4.4, S1.2
unnamed: D1.2 (A), R27.2
unnamed: Q1.2 (B), R25.2
unnamed: R5.2, R7.1, U1.1
unnamed: R15.1, R16.1
unnamed: R1.2, R2.2, R5.1, U1.2 (-)
unnamed: R7.2, R9.1, U1.6 (-)
unnamed: C2.1, U2.10 (BIAS)
unnamed: RV1.1, U2.3 (MO)
unnamed: C1.1, U2.5 (TC1)
unnamed: C1.2, U2.6 (TC2)
unnamed: R3.1, U2.7 (TR1)
unnamed: R4.1, U2.8 (TR2)
unnamed: C6.1, U3.10 (BIAS)
unnamed: RV2.1, U3.3 (MO)
unnamed: R20.1, U3.11 (SYNCO)
unnamed: C5.1, U3.5 (TC1)
unnamed: C5.2, U3.6 (TC2)
unnamed: R16.2, U3.7 (TR1)
unnamed: R19.1, U3.13 (WAVEA1)
unnamed: R19.2, U3.14 (WAVEA2)
V_saw: R2.1, U2.2 (STO)
V_sq: R10.1, R25.1, U2.9 (FSKI), U2.11 (SYNCO)
Vp: J3.1 (In), Q1.1 (C), R26.2
Vx: J2.1 (In), R9.2, U1.7
Vy: J1.1 (In), U3.2 (STO)

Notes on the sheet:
Dual Power Supply Rail
Sawtooth Shifting and Scaling Circuit
Output BNC Adapters
Pen Lift Pulse
HP8552B Horizontal Output Emulator Circuit
Sawtooth Volt-Div
HP8552B Vertical Output Emulator Circuit

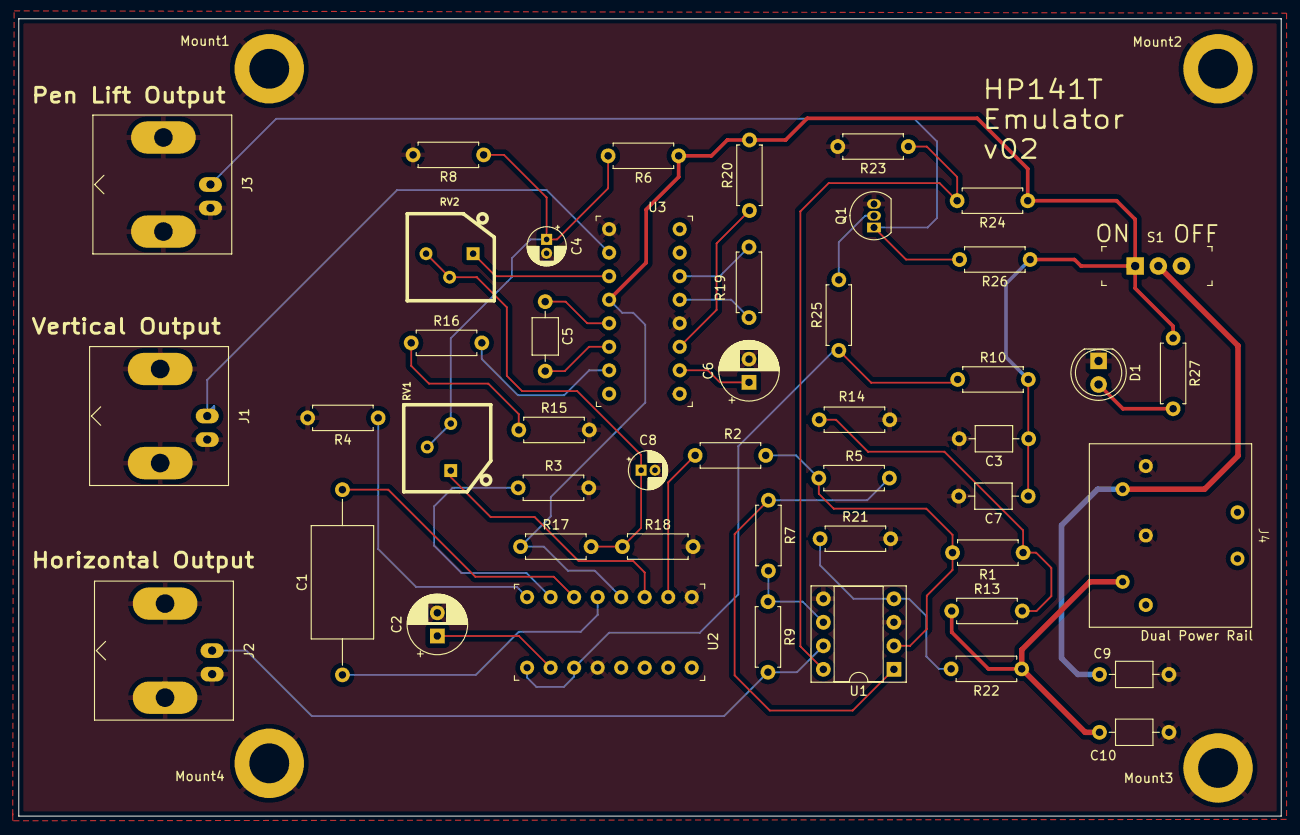
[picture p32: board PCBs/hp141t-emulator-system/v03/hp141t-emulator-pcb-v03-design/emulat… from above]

Board: 2 copper layers, 136.3 x 86.1 mm, 51 parts (0 on the bottom side), 34 nets.

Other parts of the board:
Mount1, Mount2, Mount3, Mount4: MountingHole_4.3mm_M4_DIN965_Pad

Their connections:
GND: Mount1.1, Mount2.1, Mount3.1, Mount4.1; also elsewhere on the board

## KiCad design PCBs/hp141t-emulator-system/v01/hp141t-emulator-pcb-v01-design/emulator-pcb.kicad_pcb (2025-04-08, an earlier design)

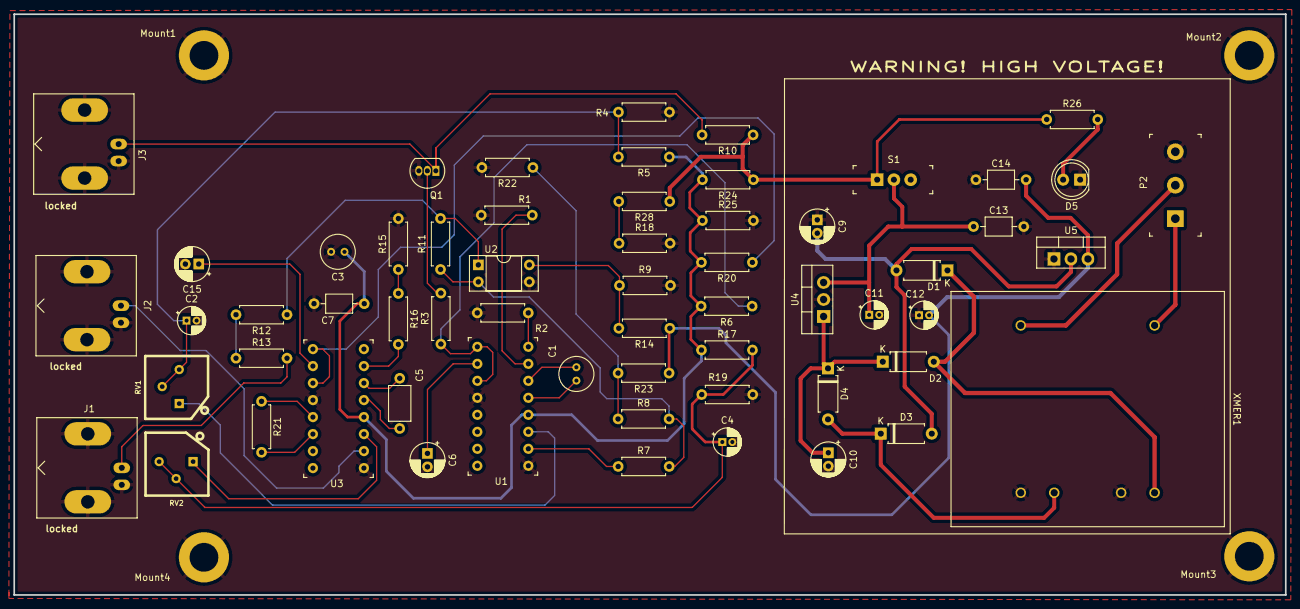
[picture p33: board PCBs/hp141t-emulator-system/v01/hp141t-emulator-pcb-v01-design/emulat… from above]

Board: 2 copper layers, 190.0 x 86.8 mm, 64 parts (0 on the bottom side), 41 nets.

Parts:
C1: 47uF; C_Radial_D5.0mm_H5.0mm_P2.00mm
C2, C4, C11, C12: 10uF; CP_Radial_D4.0mm_P1.50mm
C3: 1uF; C_Radial_D5.0mm_H5.0mm_P2.00mm
C5: 22nF; C_Axial_L5.1mm_D3.1mm_P7.50mm_Horizontal
C6, C15: 1uF; CP_Radial_D5.0mm_P2.00mm
C7: 1uF; C_Axial_L3.8mm_D2.6mm_P7.50mm_Horizontal
C9, C10: 1mF; CP_Radial_D5.0mm_P2.00mm
C13, C14: 0.1uF; C_Axial_L3.8mm_D2.6mm_P7.50mm_Horizontal
D1, D2, D3, D4: 1N4007; D_A-405_P7.62mm_Horizontal
D5: GREEN; LED_D5.0mm
J1, J2, J3: Conn_Coaxial; BNC_Amphenol_B6252HB-NPP3G-50_Horizontal
Mount1, Mount2, Mount3, Mount4: MountingHole_4.3mm_M4_DIN965_Pad
P2: Conn_WallPlug_Earth; Term_Block_1x3_P5mm
Q1: 2N2222; TO-92_Inline
R1: 1.5k; R_Axial_DIN0207_L6.3mm_D2.5mm_P7.62mm_Horizontal
R2: 1.2k; R_Axial_DIN0207_L6.3mm_D2.5mm_P7.62mm_Horizontal
R3, R7, R8: 1k; R_Axial_DIN0207_L6.3mm_D2.5mm_P7.62mm_Horizontal
R4, R5, R6, R17, R19: 5.1k; R_Axial_DIN0207_L6.3mm_D2.5mm_P7.62mm_Horizontal
R9, R10, R12, R13, R14, R18, R20, R22, R25, R28: 10k; R_Axial_DIN0207_L6.3mm_D2.5mm_P7.62mm_Horizontal
R11: 18k; R_Axial_DIN0207_L6.3mm_D2.5mm_P7.62mm_Horizontal
R15: 4.3k; R_Axial_DIN0207_L6.3mm_D2.5mm_P7.62mm_Horizontal
R16, R21: 220R; R_Axial_DIN0207_L6.3mm_D2.5mm_P7.62mm_Horizontal
R23: 110k; R_Axial_DIN0207_L6.3mm_D2.5mm_P7.62mm_Horizontal
R24: 3.3k; R_Axial_DIN0207_L6.3mm_D2.5mm_P7.62mm_Horizontal
R26: 100k; R_Axial_DIN0207_L6.3mm_D2.5mm_P7.62mm_Horizontal
RV1, RV2: 25k; BOURNS-3362P_pot
S1: EG1218; Switch_Slide_11.6x4mm_EG1218
U1, U3: XR2206CP; Socket_DIP-16_7.62mm_Conn
U2: LM358; DIP-4_W7.62mm_Socket
U4: LM7812_TO220; TO-220-3_Vertical
U5: LM7912_TO220; TO-220-3_Vertical
XMER1: 44202; 44202_MYR

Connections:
12V1: C11.1, C13.1, S1.2, U4.3 (VO)
+6V: R18.1, R28.2
+9V: C3.1, C7.1, R5.1, R6.2, R17.1, R20.2, R24.2, R25.1, U1.4 (Vcc), U3.4 (Vcc)
+12V: R10.1, R24.1, R26.1, R28.1, S1.1
-1V: R8.1, R22.1, R23.2
-6V: R9.1, R14.2, U2.4 (V-)
-12V: C12.2, C14.2, R14.1, R23.1, U5.3 (VO)
GND: C2.2, C3.2, C4.2, C6.2, C7.2, C9.1, C10.2, C11.2, C12.1, C13.2, C14.1, C15.2, D5.1 (K), J1.2 (Ext), J2.2 (Ext), J3.2 (Ext), Mount1.1, Mount2.1, Mount3.1, Mount4.1, P2.3 (EARTH), Q1.3 (E), R1.2, R2.2, R4.2, R9.2, R15.2, R18.2, R19.2, R22.2, R25.2, U1.1 (AMSI), U1.12 (GND), U2.3 (+), U3.1 (AMSI), U3.12 (GND), U4.2 (GND), U5.1 (GND), XMER1.6, XMER1.9
unnamed: C2.1, R4.1, R5.2, RV1.2, RV1.3
unnamed: C4.1, R17.2, R19.1, RV2.2, RV2.3
unnamed: C9.2, D1.2 (A), D3.2 (A), U5.2 (VI)
unnamed: D1.1 (K), D2.2 (A), XMER1.10
unnamed: C10.1, D2.1 (K), D4.1 (K), U4.1 (VI)
unnamed: D3.1 (K), D4.2 (A), XMER1.7
unnamed: D5.2 (A), R26.2
unnamed: P2.2 (AC_N), XMER1.5
unnamed: P2.1 (AC_P), XMER1.1
unnamed: Q1.2 (B), R3.2
unnamed: R11.2, R12.1, U2.1
unnamed: R15.1, R16.1
unnamed: C6.1, U1.10 (BIAS)
unnamed: RV1.1, U1.3 (MO)
unnamed: C1.1, U1.5 (TC1)
unnamed: C1.2, U1.6 (TC2)
unnamed: R1.1, U1.7 (TR1)
unnamed: R2.1, U1.8 (TR2)
unnamed: R7.2, R8.2, R11.1, U2.2 (-)
unnamed: R12.2, R13.1
unnamed: C15.1, U3.10 (BIAS)
unnamed: R20.1, U3.9 (FSKI), U3.11 (SYNCO)
unnamed: RV2.1, U3.3 (MO)
unnamed: C5.1, U3.5 (TC1)
unnamed: C5.2, U3.6 (TC2)
unnamed: R16.2, U3.7 (TR1)
unnamed: R21.1, U3.13 (WAVEA1)
unnamed: R21.2, U3.14 (WAVEA2)
V_saw: R7.1, U1.2 (STO)
V_sq: R3.1, R6.1, U1.9 (FSKI), U1.11 (SYNCO)
Vp: J3.1 (In), Q1.1 (C), R10.2
Vx: J1.1 (In), R13.2
Vy: J2.1 (In), U3.2 (STO)

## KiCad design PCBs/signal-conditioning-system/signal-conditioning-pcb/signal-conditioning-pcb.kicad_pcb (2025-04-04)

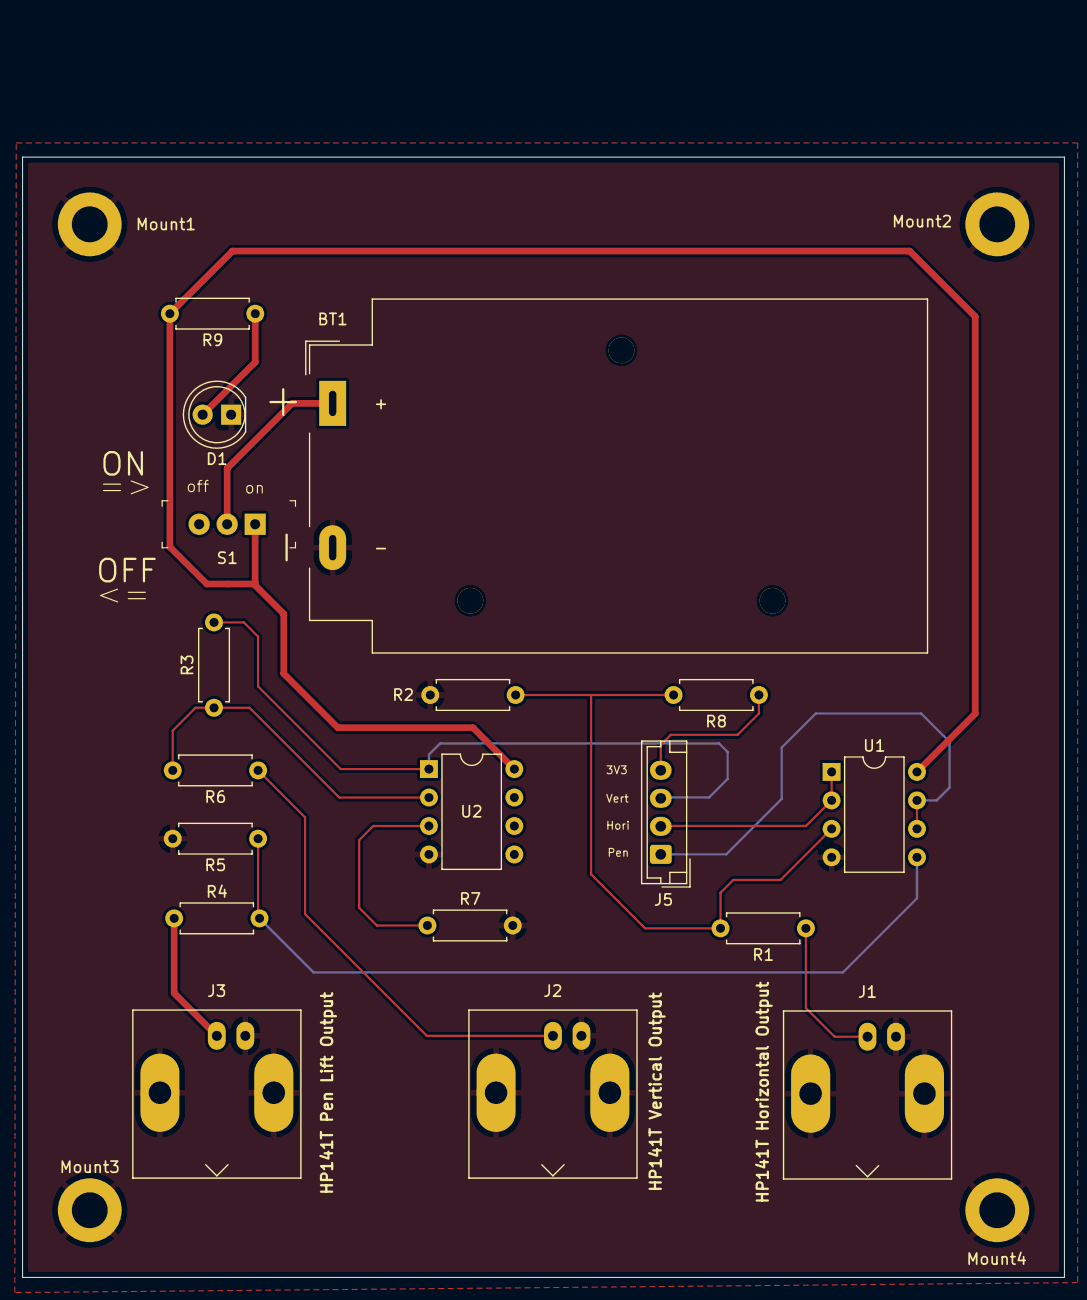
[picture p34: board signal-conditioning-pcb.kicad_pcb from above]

Board: 2 copper layers, 93.0 x 100.0 mm, 22 parts (0 on the bottom side), 15 nets.

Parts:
BT1: 9V; BatteryHolder_MPD_BA9VPC_1xPP3
D1: Green; LED_D5.0mm
J1, J2, J3: Conn_Coaxial; BNC_Amphenol_B6252HB-NPP3G-50_Horizontal
J5: Conn_01x04_Pin; JST_EH_B4B-EH-A_1x04_P2.50mm_Vertical
Mount1, Mount2, Mount3, Mount4: MountingHole_3.2mm_M3_ISO7380_Pad
R1: 100k; R_Axial_DIN0207_L6.3mm_D2.5mm_P7.62mm_Horizontal
R2: 200k; R_Axial_DIN0207_L6.3mm_D2.5mm_P7.62mm_Horizontal
R3, R5: 10k; R_Axial_DIN0207_L6.3mm_D2.5mm_P7.62mm_Horizontal
R4: 47k; R_Axial_DIN0207_L6.3mm_D2.5mm_P7.62mm_Horizontal
R6: 2.7k; R_Axial_DIN0207_L6.3mm_D2.5mm_P7.62mm_Horizontal
R7: 2.2k; R_Axial_DIN0207_L6.3mm_D2.5mm_P7.62mm_Horizontal
R8: 68k; R_Axial_DIN0207_L6.3mm_D2.5mm_P7.62mm_Horizontal
R9: 470R; R_Axial_DIN0207_L6.3mm_D2.5mm_P7.62mm_Horizontal
S1: EG1218; Switch_Slide_11.6x4mm_EG1218
U1, U2: LM358; DIP-8_W7.62mm

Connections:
3V3: J5.4, R8.1
+9V: R9.2, S1.1, U1.8 (V+), U2.8 (V+)
GND: BT1.2 (-), D1.1 (K), J1.2 (Ext), J2.2 (Ext), J3.2 (Ext), Mount1.1, Mount2.1, Mount3.1, Mount4.1, R2.2, R5.2, R7.2, U1.4 (V-), U2.4 (V-)
unnamed: BT1.1 (+), S1.2
unnamed: D1.2 (A), R9.1
unnamed: R1.2, R2.1, R8.2, U1.3 (+)
unnamed: R4.2, R5.1, U1.5 (+)
unnamed: R7.1, U2.3 (+)
unnamed: R3.1, R6.2, U2.2 (-)
V_hin: J1.1 (In), R1.1
V_hout: J5.2, U1.1, U1.2 (-)
V_penin: J3.1 (In), R4.1
V_penout: J5.1, U1.6 (-), U1.7
V_vin: J2.1 (In), R6.1
V_vout: J5.3, R3.2, U2.1

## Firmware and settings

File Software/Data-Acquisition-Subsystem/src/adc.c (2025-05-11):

#include "adc.h"
#include "stm32h7xx_hal.h" // Modified: Explicitly include STM32H7 HAL for STM32H723ZG

/* Modified: Updated comment for STM32H723ZG context
 * This code configures ADC3 and DMA2 on the STM32H723ZG to continuously convert
 * three analog signals (horizontal, vertical, pen-lift) from the HP141T spectrum
 * analyzer, storing data in a spectrogram for display. The ADC clock is 27 MHz
 * (APB2/4, system clock 216 MHz), with 12-bit resolution and a sampling rate of
 * ~675 kSPS per channel, suitable for the 300 kHz vertical output.
 */

#define ADCx                            ADC3
#define ADCx_CLK_ENABLE()               __HAL_RCC_ADC3_CLK_ENABLE()
#define DMAx_CLK_ENABLE()               __HAL_RCC_DMA2_CLK_ENABLE()
#define ADCx_CHANNEL_GPIO_CLK_ENABLE()  __HAL_RCC_GPIOF_CLK_ENABLE()

#define ADCx_FORCE_RESET()              __HAL_RCC_ADC_FORCE_RESET()
#define ADCx_RELEASE_RESET()            __HAL_RCC_ADC_RELEASE_RESET()

/* Definition for ADCx Channel Pins */
#define ADCx_CHANNEL_PIN                GPIO_PIN_10 // Horizontal (V_x), PF10
#define ADCx_CHANNEL_PIN2               GPIO_PIN_9  // Vertical (V_y), PF9
#define ADCx_CHANNEL_PIN3               GPIO_PIN_8  // Modified: Added for pen-lift (V_z), PF8
#define ADCx_CHANNEL_GPIO_PORT          GPIOF

/* Definition for ADCx's Channels */
#define ADCx_CHANNEL                    ADC_CHANNEL_8  // Horizontal
#define ADCx_CHANNEL2                   ADC_CHANNEL_7  // Vertical
#define ADCx_CHANNEL3                   ADC_CHANNEL_6  // Modified: Pen-lift

/* Definition for ADCx's DMA */
#define ADCx_DMA_CHANNEL                DMA_CHANNEL_2
#define ADCx_DMA_STREAM                 DMA2_Stream0

/* Definition for ADCx's NVIC */
#define ADCx_DMA_IRQn                   DMA2_Stream0_IRQn
#define ADCx_DMA_IRQHandler             DMA2_Stream0_IRQHandler

ADC_HandleTypeDef    AdcHandle;

#define ADC_BUF_SIZE 3072 // Modified: Increased to 3072 (1024 samples/channel for 3 channels)

volatile uint32_t adc_buffer[ADC_BUF_SIZE] = {0};

int adc_last_conversion_complete = 0;

/* Modified: Added error flag for better error handling */
volatile int adc_error_flag = 0;

/**
 * @brief  This function handles DMA interrupt request.
 * @param  None
 * @retval None
 */
void ADCx_DMA_IRQHandler(void) {
  HAL_DMA_IRQHandler(AdcHandle.DMA_Handle);
}

/**
 * @brief  Error handler for ADC initialization or configuration failures.
 * @param  None
 * @retval None
 */
void adc_error_handler(void) {
    adc_error_flag = 1; // Modified: Set error flag instead of infinite loop
    // Optionally add debug output (e.g., UART) in production
    while(1) {} // Retain halt for critical errors
}

spectrogram_t *adc_spectrogram = 0;

/**
 * @brief  Sets the spectrogram structure for data storage.
 * @param  s: Pointer to spectrogram structure
 * @retval None
 */
void adc_set_spectrogram(spectrogram_t *s) {
    adc_spectrogram = s;
}

/**
 * @brief  Initializes ADC3 and DMA for continuous conversion on three channels.
 * @param  None
 * @retval 0 on success, -1 on failure
 */
int adc_init(void) {
    ADC_ChannelConfTypeDef sConfig;

    AdcHandle.Instance = ADCx;
    AdcHandle.Init.ClockPrescaler = ADC_CLOCKPRESCALER_PCLK_DIV4; // 27 MHz ADC clock
    AdcHandle.Init.Resolution = ADC_RESOLUTION_12B;
    AdcHandle.Init.ScanConvMode = ENABLE; // Scan multiple channels
    AdcHandle.Init.ContinuousConvMode = ENABLE;
    AdcHandle.Init.DiscontinuousConvMode = DISABLE;
    AdcHandle.Init.NbrOfDiscConversion = 0;
    AdcHandle.Init.ExternalTrigConvEdge = ADC_EXTERNALTRIGCONVEDGE_NONE;
    AdcHandle.Init.ExternalTrigConv = ADC_SOFTWARE_START; // Modified: Use software trigger
    AdcHandle.Init.DataAlign = ADC_DATAALIGN_RIGHT;
    AdcHandle.Init.NbrOfConversion = 3; // Modified: Three channels (V_x, V_y, V_z)
    AdcHandle.Init.DMAContinuousRequests = ENABLE;
    AdcHandle.Init.EOCSelection = DISABLE;

    if (HAL_ADC_Init(&AdcHandle) != HAL_OK) {
        adc_error_handler();
        return -1;
    }

    /* Configure ADC channel for horizontal (V_x) */
    sConfig.Channel = ADCx_CHANNEL;
    sConfig.Rank = 1;
    sConfig.SamplingTime = ADC_SAMPLETIME_28CYCLES; // ~1.48 µs conversion time
    sConfig.Offset = 0;
    if (HAL_ADC_ConfigChannel(&AdcHandle, &sConfig) != HAL_OK) {
        adc_error_handler();
        return -1;
    }

    /* Configure ADC channel for vertical (V_y) */
    sConfig.Channel = ADCx_CHANNEL2;
    sConfig.Rank = 2;
    sConfig.SamplingTime = ADC_SAMPLETIME_28CYCLES;
    sConfig.Offset = 0;
    if (HAL_ADC_ConfigChannel(&AdcHandle, &sConfig) != HAL_OK) {
        adc_error_handler();
        return -1;
    }

    /* Modified: Configure ADC channel for pen-lift (V_z) */
    sConfig.Channel = ADCx_CHANNEL3;
    sConfig.Rank = 3;
    sConfig.SamplingTime = ADC_SAMPLETIME_28CYCLES;
    sConfig.Offset = 0;
    if (HAL_ADC_ConfigChannel(&AdcHandle, &sConfig) != HAL_OK) {
        adc_error_handler();
        return -1;
    }

    /* Start ADC with DMA */
    if (HAL_ADC_Start_DMA(&AdcHandle, (uint32_t*)adc_buffer, ADC_BUF_SIZE) != HAL_OK) {
        adc_error_handler();
        return -1;
    }

    return 0;
}

volatile int prev_x = 0;

extern int pending_normalization;

/**
 * @brief  Callback for half buffer DMA transfer complete.
 * @param  AdcHandle: ADC handle
 * @retval None
 */
void HAL_ADC_ConvHalfCpltCallback(ADC_HandleTypeDef* AdcHandle) {
    for (int j = 0; j < ADC_BUF_SIZE/6; ++j) { // Modified: Adjust for 3 channels
        uint32_t x_val = adc_buffer[j*3];     // Horizontal (V_x)
        uint32_t y_val = adc_buffer[j*3+1];   // Vertical (V_y)
        uint32_t z_val = adc_buffer[j*3+2];   // Modified: Pen-lift (V_z)
        x_val = (x_val * adc_spectrogram->npoints) / 4096;
        y_val = adc_spectrogram->size_y - (adc_spectrogram->size_y * y_val) / 4096;
        z_val = z_val > 2048 ? 1 : 0; // Modified: Threshold pen-lift at mid-scale (~1.65 V)
        if (x_val < 5) prev_x = 0;
        if (x_val > prev_x && z_val == 0) { // Modified: Only plot if pen is down
            if (pending_normalization) {
                adc_spectrogram->data_normal[x_val] = adc_spectrogram->size_y/2 - y_val;
            }
            adc_spectrogram->data[x_val] = y_val + adc_spectrogram->data_normal[x_val];
            prev_x = x_val;
        }
    }
}
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

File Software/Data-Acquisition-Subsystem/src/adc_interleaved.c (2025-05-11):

#include "stm32h7xx_hal.h" // STM32H7 HAL for STM32H723ZG

/* 
 * Configures ADC1 and ADC2 on STM32H723ZG in double-interleaved mode (7.2 MSPS, 16-bit)
 * to sample HP141T signals: horizontal (V_x), vertical (V_y), pen-lift (V_z).
 * System clock: 480 MHz, ADC clock: 36 MHz, sampling rate: 7.2 MSPS.
 * DMA2 transfers interleaved data to a buffer, processed for spectrogram display.
 */

#define ADCx_MASTER                     ADC1
#define ADCx_SLAVE                      ADC2
#define ADCx_CLK_ENABLE()               do { __HAL_RCC_ADC12_CLK_ENABLE(); } while(0)
#define DMAx_CLK_ENABLE()               __HAL_RCC_DMA2_CLK_ENABLE()
#define ADCx_CHANNEL_GPIO_CLK_ENABLE()  __HAL_RCC_GPIOF_CLK_ENABLE()

#define ADCx_FORCE_RESET()              __HAL_RCC_ADC12_FORCE_RESET()
#define ADCx_RELEASE_RESET()            __HAL_RCC_ADC12_RELEASE_RESET()

/* GPIO Pins for ADC Channels */
#define ADCx_CHANNEL_PIN                GPIO_PIN_10 // V_x, PF10 (ADC1_INP8)
#define ADCx_CHANNEL_PIN2               GPIO_PIN_9  // V_y, PF9 (ADC1_INP7)
#define ADCx_CHANNEL_PIN3               GPIO_PIN_8  // V_z, PF8 (ADC1_INP6)
#define ADCx_CHANNEL_GPIO_PORT          GPIOF

/* ADC Channels */
#define ADCx_CHANNEL                    ADC_CHANNEL_8  // V_x
#define ADCx_CHANNEL2                   ADC_CHANNEL_7  // V_y
#define ADCx_CHANNEL3                   ADC_CHANNEL_6  // V_z

/* DMA Configuration */
#define ADCx_DMA_CHANNEL                DMA_REQUEST_ADC1 // Master ADC1
#define ADCx_DMA_STREAM                 DMA2_Stream0
#define ADCx_DMA_IRQn                   DMA2_Stream0_IRQn
#define ADCx_DMA_IRQHandler             DMA2_Stream0_IRQHandler

ADC_HandleTypeDef    AdcHandleMaster;
ADC_HandleTypeDef    AdcHandleSlave;

#define ADC_BUF_SIZE 8192 // 8192 samples (~1.14 ms at 7.2 MSPS, 2730 samples/channel)

volatile uint16_t adc_buffer[ADC_BUF_SIZE] = {0}; // 16-bit for interleaved data

volatile int adc_error_flag = 0;

/**
 * @brief  Handles DMA interrupt request for ADC1.
 * @param  None
 * @retval None
 */
void ADCx_DMA_IRQHandler(void) {
    HAL_DMA_IRQHandler(AdcHandleMaster.DMA_Handle);
}

/**
 * @brief  Error handler for ADC initialization or configuration failures.
 * @param  None
 * @retval None
 */
void adc_error_handler(void) {
    adc_error_flag = 1;
    while(1) {} // Add debug output in production
}

spectrogram_t *adc_spectrogram = 0;

/**
 * @brief  Sets the spectrogram structure for data storage.
 * @param  s: Pointer to spectrogram structure
 * @retval None
 */
void adc_set_spectrogram(spectrogram_t *s) {
    adc_spectrogram = s;
}

/**
 * @brief  Initializes ADC1/ADC2 in double-interleaved mode and DMA.
 * @param  None
 * @retval 0 on success, -1 on failure
 */
int adc_init(void) {
    ADC_ChannelConfTypeDef sConfig;
    ADC_MultiModeTypeDef multiMode;

    /* Configure ADC1 (Master) */
    AdcHandleMaster.Instance = ADCx_MASTER;
    AdcHandleMaster.Init.ClockPrescaler = ADC_CLOCKPRESCALER_PCLK_DIV4; // ~36 MHz
    AdcHandleMaster.Init.Resolution = ADC_RESOLUTION_16B; // 16-bit
    AdcHandleMaster.Init.ScanConvMode = ENABLE;
    AdcHandleMaster.Init.ContinuousConvMode = ENABLE;
    AdcHandleMaster.Init.DiscontinuousConvMode = DISABLE;
    AdcHandleMaster.Init.ExternalTrigConvEdge = ADC_EXTERNALTRIGCONVEDGE_NONE;
    AdcHandleMaster.Init.ExternalTrigConv = ADC_SOFTWARE_START;
    AdcHandleMaster.Init.DataAlign = ADC_DATAALIGN_RIGHT;
    AdcHandleMaster.Init.NbrOfConversion = 3; // V_x, V_y, V_z
    AdcHandleMaster.Init.DMAContinuousRequests = ENABLE;
    AdcHandleMaster.Init.EOCSelection = ADC_EOC_SEQ_CONV;
    AdcHandleMaster.Init.Overrun = ADC_OVR_DATA_OVERWRITTEN;

    if (HAL_ADC_Init(&AdcHandleMaster) != HAL_OK) {
        adc_error_handler();
        return -1;
    }

    /* Configure ADC2 (Slave) */
    AdcHandleSlave.Instance = ADCx_SLAVE;
    AdcHandleSlave.Init = AdcHandleMaster.Init; // Same config as master
    if (HAL_ADC_Init(&AdcHandleSlave) != HAL_OK) {
        adc_error_handler();
        return -1;
    }

    /* Configure double-interleaved mode */
    multiMode.Mode = ADC_DUALMODE_INTERL_FAST; // Fast interleaved mode
    multiMode.DualModeData = ADC_DUALMODEDATAFORMAT_32_10_BITS;
    multiMode.TwoSamplingDelay = ADC_TWOSAMPLINGDELAY_1CYCLE;
    if (HAL_ADCEx_MultiModeConfigChannel(&AdcHandleMaster, &multiMode) != HAL_OK) {
        adc_error_handler();
        return -1;
    }

    /* Configure channels for ADC1 */
    sConfig.SamplingTime = ADC_SAMPLETIME_2CYCLES_5; // Fast sampling for 7.2 MSPS
    sConfig.Offset = 0;

    /* V_x (Horizontal) */
    sConfig.Channel = ADCx_CHANNEL;
    sConfig.Rank = 1;
    if (HAL_ADC_ConfigChannel(&AdcHandleMaster, &sConfig) != HAL_OK) {
        adc_error_handler();
        return -1;
    }

    /* V_y (Vertical) */
    sConfig.Channel = ADCx_CHANNEL2;
    sConfig.Rank = 2;
    if (HAL_ADC_ConfigChannel(&AdcHandleMaster, &sConfig) != HAL_OK) {
        adc_error_handler();
        return -1;
    }

    /* V_z (Pen-lift) */
    sConfig.Channel = ADCx_CHANNEL3;
    sConfig.Rank = 3;
    if (HAL_ADC_ConfigChannel(&AdcHandleMaster, &sConfig) != HAL_OK) {
        adc_error_handler();
        return -1;
    }

    /* Start ADC with DMA (master only) */
    if (HAL_ADCEx_MultiModeStart_DMA(&AdcHandleMaster, (uint32_t*)adc_buffer, ADC_BUF_SIZE) != HAL_OK) {
        adc_error_handler();
        return -1;
    }

    return 0;
}

volatile int prev_x = 0;
extern int pending_normalization;

/**
 * @brief  Callback for half buffer DMA transfer complete.
 * @param  AdcHandle: ADC handle
 * @retval None
 */
void HAL_ADC_ConvHalfCpltCallback(ADC_HandleTypeDef* AdcHandle) {
    for (int j = 0; j < ADC_BUF_SIZE/6; ++j) {
        uint32_t x_val = adc_buffer[j*3];     // V_x
        uint32_t y_val = adc_buffer[j*3+1];   // V_y
        uint32_t z_val = adc_buffer[j*3+2];   // V_z
        x_val = (x_val * adc_spectrogram->npoints) / 65536; // 16-bit scaling
        y_val = adc_spectrogram->size_y - (adc_spectrogram->size_y * y_val) / 65536;
        z_val = z_val > 32768 ? 1 : 0; // Threshold at mid-scale (~1.65 V)
        if (x_val < 5) prev_x = 0;
        if (x_val > prev_x && z_val == 0) {
            if (pending_normalization) {
                adc_spectrogram->data_normal[x_val] = adc_spectrogram->size_y/2 - y_val;
            }
            adc_spectrogram->data[x_val] = y_val + adc_spectrogram->data_normal[x_val];
            prev_x = x_val;
        }
    }
}
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

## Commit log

2025-04-04 Completed Signal Conditioning PCB design.
    [signal-conditioning-pcb-B_Cu.gbl, signal-conditioning-pcb-B_Mask.gbs, signal-conditioning-pcb-B_Paste.gbp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]
2025-04-04 Added GND mounting holes to SigConditioningCirc
    [signal-conditioning-pcb-B_Cu.gbl, signal-conditioning-pcb-B_Mask.gbs, signal-conditioning-pcb-B_Paste.gbp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]
2025-04-08 Completed the HP141T Emulator Board
    [emulator-pcb-B_Cu.gbl, emulator-pcb-B_Mask.gbs, emulator-pcb-B_Paste.gbp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]
2025-04-10 Updated Emulator PCB from v01 to v02. Power supply change.
    [emulator-pcb-B_Cu.gbl, emulator-pcb-B_Mask.gbs, emulator-pcb-B_Paste.gbp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]
2025-04-10 Removed voltage divider. Added 0.1uF power capacitors.
    [emulator-pcb-B_Cu.gbl, emulator-pcb-B_Mask.gbs, emulator-pcb-B_Paste.gbp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]
2025-04-22 Updated hp141t emulator. Removed +12V to +9V divider
    [emulator-pcb-B_Cu.gbl, emulator-pcb-B_Mask.gbs, emulator-pcb-B_Paste.gbp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]
2025-04-25 Uploaded MATLAB ADC sim files and results.
2025-04-25 Uploaded MATLAB ADC simulation for STM32H723ZG
2025-05-11 Completed the adc.c module in the Software directory.
2025-05-29 Complete with presentation slides and poster.
    [das-data_01.csv, das-data_02.csv, das-data_03.csv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]
